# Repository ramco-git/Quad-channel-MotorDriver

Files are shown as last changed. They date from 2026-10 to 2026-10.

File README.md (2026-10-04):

# クアッドチャンネルモータードライバ (超はんだもりもり森鴎外!）

クアッドチャネルのDCブラシ付きモータードライバ基板です。内臓MCUにSTM32F405RGT6を使用し、4つのエンコーダ入力と1つのUART、1つのclassic CANに対応しています。内部でのPID制御が可能です。エンコーダはインクリメンタル式にのみ対応し、ゼロ校正に必要なZ相を引き出しています。すべての通信線は5Vトレラントピンに接続されています。入力信号をダイオードによりミックスしているため、内部から、又は外部から直接PWMとDIR信号を入力して動作させることができます。

## 仕様
・MCUにSTM32F405RGT6を使用し、回転数、位置制御を基板単体で可能です。
| 機能 | 個数 | 備考 |
|-:|-|-|
| モータードライバ | 4 | 30V、連続10A(なお性能試験を行っていないため、詳細は不明) |
| モーター出力 | 4 | XT60PW-F |
| 電源入力 | 1 | XT60PW-M |
|　MCU | 1 | STM32F405RGT6 |
| ユーザーLED | 1 | RGBの一体型チップ |
| ユーザーボタン | 1 | CANのID設定などに使用 |

## 信号線、マイコンのピンアサイン、コネクタの種類、番号
 
| 機能 | ピン | コネクタ種類 | パッドナンバー | 備考 |
|-:|-|-|-|-|
| CAN | TX(PB9) RX(PB8) | S04B-XASK-1,B04B-XASK-1 | J18,J19 | 
| UART | TX(PB10) RX(PB11) | DF1BZ-4P-2.5DSA | J6 |
| エンコーダ-1 | A(PA8) B(PA9) Z(PC0) | S05B-PASK-2 | J1 | TIM1 |
| エンコーダ-2 | A(PA0) B(PA1) Z(PC1) | S05B-PASK-2 | J2 | TIM2 |
| エンコーダ-3 | A(PA6) B(PA7) Z(PC2) | S05B-PASK-2 | J3 | TIM3 |
| エンコーダ-4 | A(PB6) B(PB7) Z(PC3) | S05B-PASK-2 | J4 | TIM4 |
| PWM-1(内臓MCUから) | PWM(PC6) DIR(PB12) | - | - | TIM8-CH1 |
| PWM-2(内臓MCUから) | PWM(PC7) DIR(PB13) | - | - | TIM8-CH2 |
| PWM-3(内臓MCUから) | PWM(PC8) DIR(PA10) | - | - | TIM8-CH3 |
| PWM-4(内臓MCUから) | PWM(PC9) DIR(PA11) | - | - | TIM8-CH4 |
| PWM-1(外部入力から) | DIR(1ピン) PWM(2ピン) GND(3ピン) | B03B-XASK-1 | J14 | - |
| PWM-2(外部入力から) | DIR(1ピン) PWM(2ピン) GND(3ピン) | B03B-XASK-1 | J15 | - |
| PWM-3(外部入力から) | DIR(1ピン) PWM(2ピン) GND(3ピン) | B03B-XASK-1 | J16 | - |
| PWM-4(外部入力から) | DIR(1ピン) PWM(2ピン) GND(3ピン) | B03B-XASK-1 | J17 | - |
| マイコン電源入力 | 12V(未使用,1ピン) 5V(2ピン) GND(3ピン) | B3B-XH-A | J7 | - |
| ユーザーLED | 赤(PB14) 緑(PA3) 青(PB15) | | D2 | TIMに接続されている |
| ユーザーボタン | (PC15) | - | SW2 | - | マイコン側でプルアップする |

## 内部ファームウェア
・現在調整中です。しばらくお待ちください。

## 名前の由来
大電流に対応させるため、銅線をバスバーとして使用した。その結果、基板がはんだだらけになってしまった。「超」はんだもりもり森鷗外!が誕生した。

## 以前の問題
・PWM,DIR信号ミックスに使用したBAT54CTのフットプリントのサイズミス
・部品番号の煩雑性

公開版では改善されています。

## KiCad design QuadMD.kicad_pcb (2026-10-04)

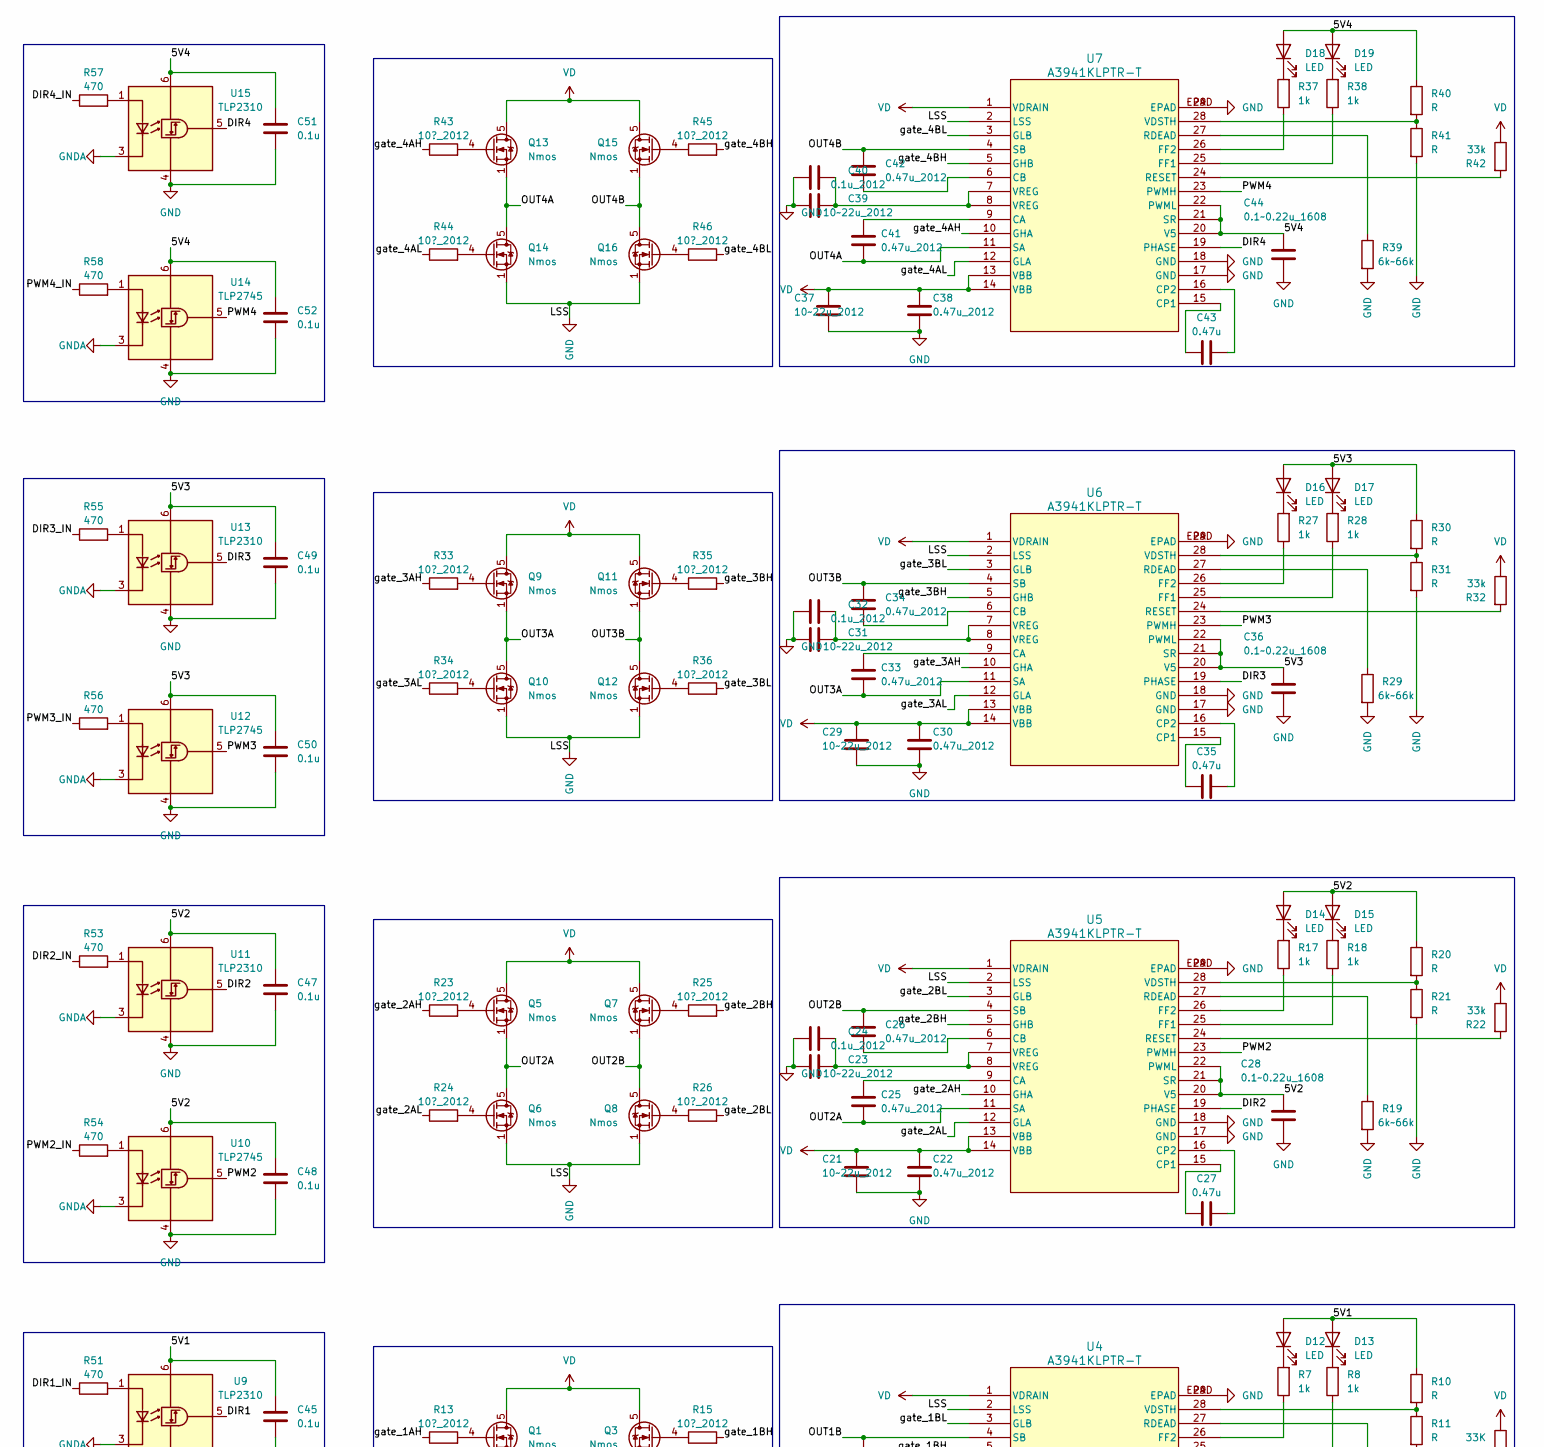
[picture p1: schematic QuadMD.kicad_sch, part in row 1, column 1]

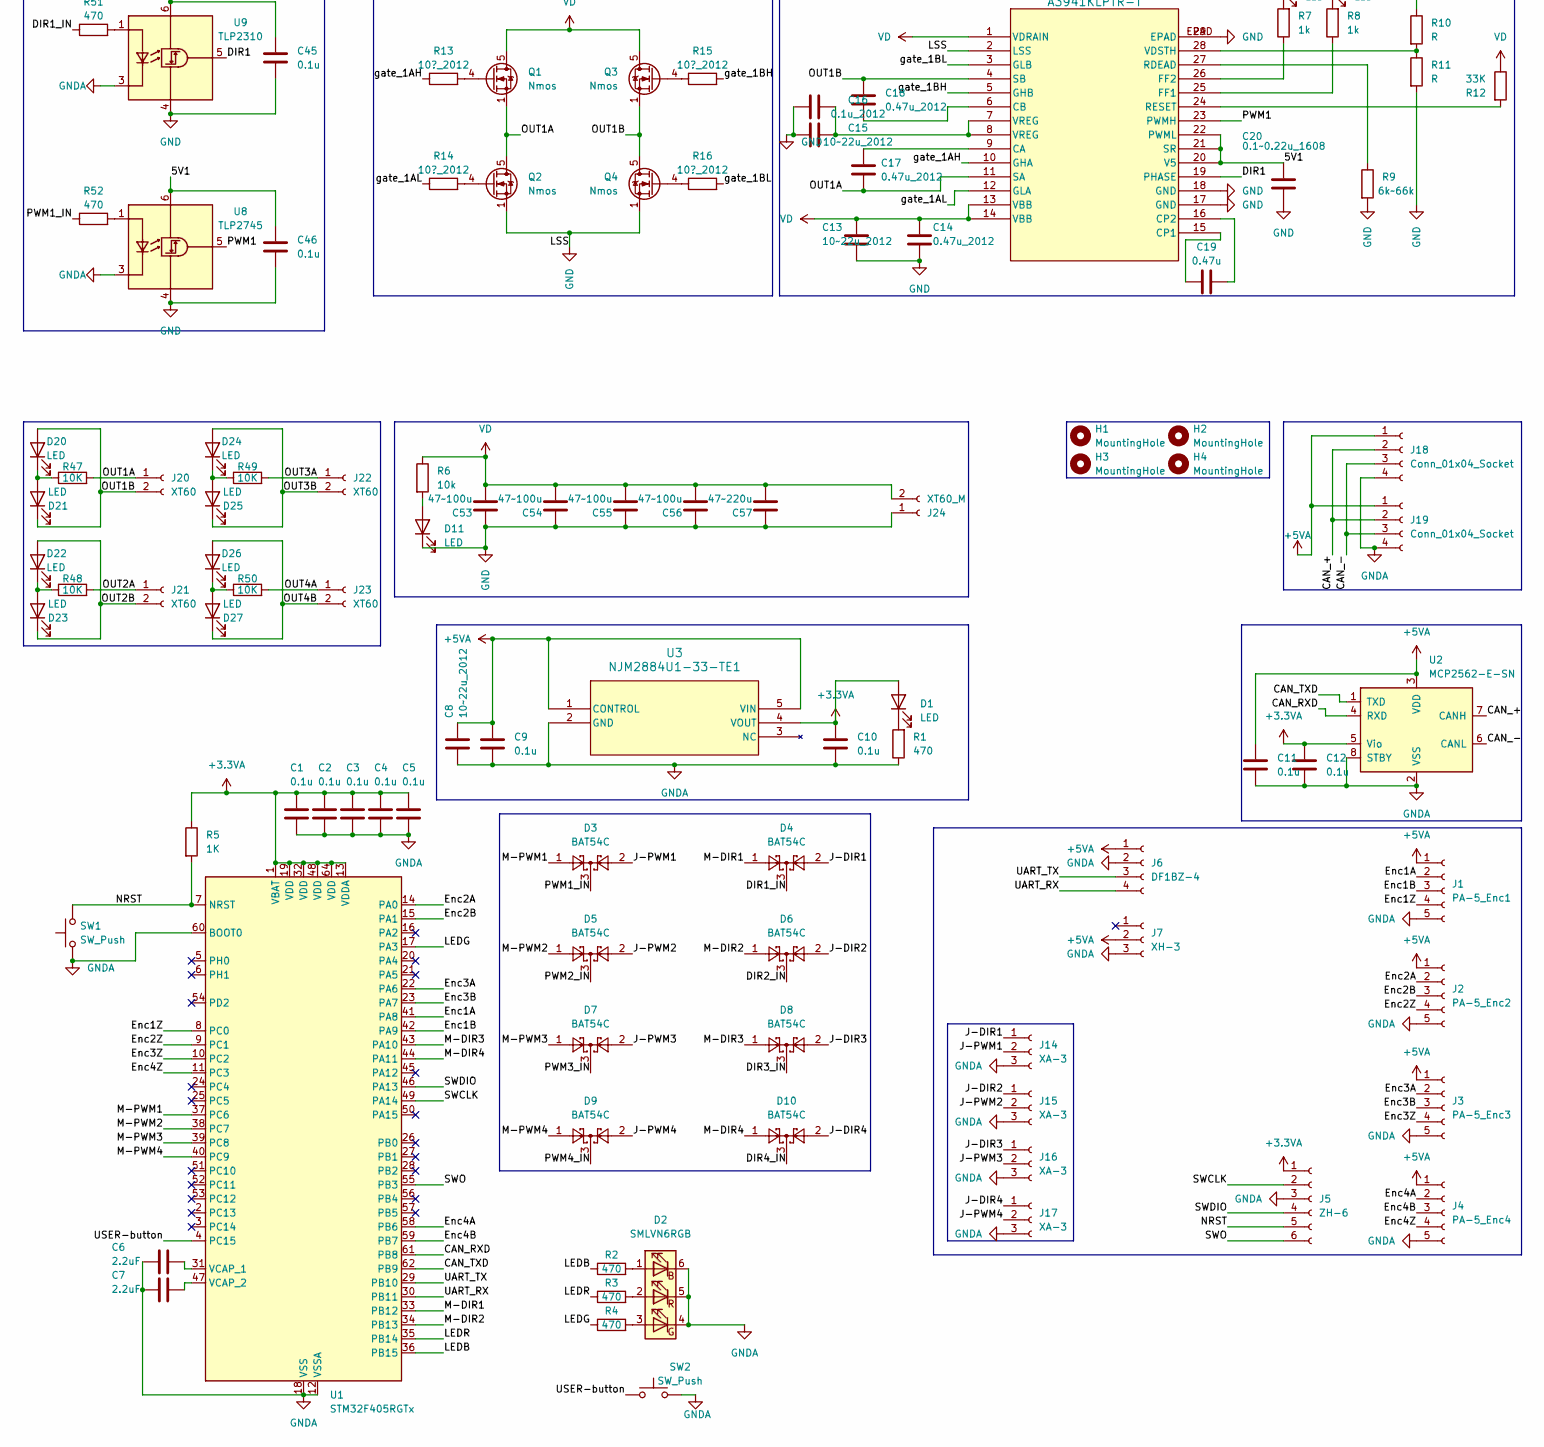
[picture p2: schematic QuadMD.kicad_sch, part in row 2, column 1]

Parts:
C1, C2, C3, C4, C5, C9, C10, C11, C12, C45, C46, C47, C48, C49, C50, C51, C52: 0.1u; C_0603_1608Metric
C6, C7: 2.2uF; C_0603_1608Metric
C8, C13, C15, C21, C23, C29, C31, C37, C39: 10~22u_2012; C_0805_2012Metric
C14, C17, C18, C22, C25, C26, C30, C33, C34, C38, C41, C42: 0.47u_2012; C_0805_2012Metric
C16, C24, C32, C40: 0.1u_2012; C_0805_2012Metric
C19, C27, C35, C43: 0.47u; C_0805_2012Metric
C20, C28, C36, C44: 0.1~0.22u_1608; C_0603_1608Metric
C53, C54, C55, C56: 47~100u; CP_Elec_6.3x5.7
C57: 47~220u; CP_Elec_10x10.5
D1, D11, D12, D13, D14, D15, D16, D17, D18, D19: LED; LED_0603_1608Metric
D2: SMLVN6RGB; LED_ROHM_SMLVN6
D3, D4, D5, D6, D7, D8, D9, D10: BAT54C; SOT-523
D20, D21, D22, D23, D24, D25, D26, D27: LED; LED_0805_2012Metric
H1, H2, H3, H4: MountingHole; MountingHole_M3_FBMask
J1: PA-5_Enc1; CONN_S05B-PASK_PA_JST
J2: PA-5_Enc2; CONN_S05B-PASK_PA_JST
J3: PA-5_Enc3; CONN_S05B-PASK_PA_JST
J4: PA-5_Enc4; CONN_S05B-PASK_PA_JST
J5: ZH-6; JST_ZH_B6B-ZR_1x06_P1.50mm_Vertical
J6: DF1BZ-4; CON4_1X4_U_DF1BZ
J7: XH-3; JST_XH_B3B-XH-A_1x03_P2.50mm_Vertical
J14, J15, J16, J17: XA-3; JST_XA_B03B-XASK-1_1x03_P2.50mm_Vertical
J18: Conn_01x04_Socket; JST_XA_B04B-XASK-1_1x04_P2.50mm_Vertical
J19: Conn_01x04_Socket; JST_XA_S04B-XASK-1N-BN_1x04_P2.50mm_Horizontal
J20, J21, J22, J23: XT60; AMASS_XT60PW-F_1x02_P7.20mm_Horizontal
J24: XT60_M; AMASS_XT60PW-M_1x02_P7.20mm_Horizontal
Q1, Q2, Q3, Q4, Q5, Q6, Q7, Q8, Q9, Q10, Q11, Q12, Q13, Q14, Q15, Q16: Nmos; PQFN-8-EP_6x5mm_P1.27mm_Generic
R1, R2, R3, R4, R51, R52, R53, R54, R55, R56, R57, R58: 470; R_0603_1608Metric
R5: 1K; R_0603_1608Metric
R6: 10k; R_0603_1608Metric
R7, R8, R17, R18, R27, R28, R37, R38: 1k; R_0603_1608Metric
R9, R19, R29, R39: 6k~66k; R_0603_1608Metric
R10, R11, R20, R21, R30, R31, R40, R41: R; R_0603_1608Metric
R12: 33K; R_0603_1608Metric
R13, R14, R15, R16, R23, R24, R25, R26, R33, R34, R35, R36, R43, R44, R45, R46: 10?_2012; R_0805_2012Metric
R22, R32, R42: 33k; R_0603_1608Metric
R47, R48, R49, R50: 10K; R_0603_1608Metric
SW1, SW2: SW_Push; SW_Push_SPST_NO_Alps_SKRK
U1: STM32F405RGTx; LQFP-64_10x10mm_P0.5mm
U2: MCP2562-E-SN; SOIC-8_3.9x4.9mm_P1.27mm
U3: NJM2884U1-33-TE1; SOT-89-5
U4, U5, U6, U7: A3941KLPTR-T; TSSOP-28-PAD_TH
U8, U10, U12, U14: TLP2745; SO-6L_10x3.84mm_P1.27mm
U9, U11, U13, U15: TLP2310; SO-5-6_4.55x3.7mm_P1.27mm

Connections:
+3.3VA: C1.1, C2.1, C3.1, C4.1, C5.1, C10.1, C12.1, D1.2 (A), J5.1, R5.1, U1.1 (VBAT), U1.13 (VDDA), U1.19 (VDD), U1.32 (VDD), U1.48 (VDD), U1.64 (VDD), U2.5 (Vio), U3.4 (VOUT)
+5VA: C8.1, C9.1, C11.1, J1.1, J2.1, J3.1, J4.1, J6.1, J7.2, J18.1, J19.1, U2.3 (VDD), U3.1 (CONTROL), U3.5 (VIN)
/5V1: C20.2, C45.2, C46.2, D12.2 (A), D13.2 (A), R10.1, U4.20 (V5), U4.21 (SR), U4.22 (PWML), U8.6 (VDD), U9.6 (VDD)
/5V2: C28.2, C47.2, C48.2, D14.2 (A), D15.2 (A), R20.1, U5.20 (V5), U5.21 (SR), U5.22 (PWML), U10.6 (VDD), U11.6 (VDD)
/5V3: C36.2, C49.2, C50.2, D16.2 (A), D17.2 (A), R30.1, U6.20 (V5), U6.21 (SR), U6.22 (PWML), U12.6 (VDD), U13.6 (VDD)
/5V4: C44.2, C51.2, C52.2, D18.2 (A), D19.2 (A), R40.1, U7.20 (V5), U7.21 (SR), U7.22 (PWML), U14.6 (VDD), U15.6 (VDD)
/CAN_+: J18.2, J19.2, U2.7 (CANH)
/CAN_-: J18.3, J19.3, U2.6 (CANL)
/CAN_RXD: U1.61 (PB8), U2.4 (RXD)
/CAN_TXD: U1.62 (PB9), U2.1 (TXD)
/DIR1: U4.19 (PHASE), U9.5 (VO)
/DIR1_IN: D4.3, R51.1
/DIR2: U5.19 (PHASE), U11.5 (VO)
/DIR2_IN: D6.3, R53.1
/DIR3: U6.19 (PHASE), U13.5 (VO)
/DIR3_IN: D8.3, R55.1
/DIR4: U7.19 (PHASE), U15.5 (VO)
/DIR4_IN: D10.3, R57.1
/Enc1A: J1.2, U1.41 (PA8)
/Enc1B: J1.3, U1.42 (PA9)
/Enc1Z: J1.4, U1.8 (PC0)
/Enc2A: J2.2, U1.14 (PA0)
/Enc2B: J2.3, U1.15 (PA1)
/Enc2Z: J2.4, U1.9 (PC1)
/Enc3A: J3.2, U1.22 (PA6)
/Enc3B: J3.3, U1.23 (PA7)
/Enc3Z: J3.4, U1.10 (PC2)
/Enc4A: J4.2, U1.58 (PB6)
/Enc4B: J4.3, U1.59 (PB7)
/Enc4Z: J4.4, U1.11 (PC3)
/J-DIR1: D4.2, J14.1
/J-DIR2: D6.2, J15.1
/J-DIR3: D8.2, J16.1
/J-DIR4: D10.2, J17.1
/J-PWM1: D3.2, J14.2
/J-PWM2: D5.2, J15.2
/J-PWM3: D7.2, J16.2
/J-PWM4: D9.2, J17.2
/LEDB: R2.1, U1.36 (PB15)
/LEDG: R4.1, U1.17 (PA3)
/LEDR: R3.1, U1.35 (PB14)
/M-DIR1: D4.1, U1.33 (PB12)
/M-DIR2: D6.1, U1.34 (PB13)
/M-DIR3: D8.1, U1.43 (PA10)
/M-DIR4: D10.1, U1.44 (PA11)
/M-PWM1: D3.1, U1.37 (PC6)
/M-PWM2: D5.1, U1.38 (PC7)
/M-PWM3: D7.1, U1.39 (PC8)
/M-PWM4: D9.1, U1.40 (PC9)
/NRST: J5.5, R5.2, SW1.2, U1.7 (NRST)
/OUT1A: C17.1, J20.1, Q1.1 (S), Q1.2 (S), Q1.3 (S), Q2.5 (D), R47.2, U4.11 (SA)
/OUT1B: C18.2, D20.2 (A), D21.1 (K), J20.2, Q3.1 (S), Q3.2 (S), Q3.3 (S), Q4.5 (D), U4.4 (SB)
/OUT2A: C25.1, J21.1, Q5.1 (S), Q5.2 (S), Q5.3 (S), Q6.5 (D), R48.2, U5.11 (SA)
/OUT2B: C26.2, D22.2 (A), D23.1 (K), J21.2, Q7.1 (S), Q7.2 (S), Q7.3 (S), Q8.5 (D), U5.4 (SB)
/OUT3A: C33.1, J22.1, Q9.1 (S), Q9.2 (S), Q9.3 (S), Q10.5 (D), R49.2, U6.11 (SA)
/OUT3B: C34.2, D24.2 (A), D25.1 (K), J22.2, Q11.1 (S), Q11.2 (S), Q11.3 (S), Q12.5 (D), U6.4 (SB)
/OUT4A: C41.1, J23.1, Q13.1 (S), Q13.2 (S), Q13.3 (S), Q14.5 (D), R50.2, U7.11 (SA)
/OUT4B: C42.2, D26.2 (A), D27.1 (K), J23.2, Q15.1 (S), Q15.2 (S), Q15.3 (S), Q16.5 (D), U7.4 (SB)
/PWM1: U4.23 (PWMH), U8.5 (VO)
/PWM1_IN: D3.3, R52.1
/PWM2: U5.23 (PWMH), U10.5 (VO)
/PWM2_IN: D5.3, R54.1
/PWM3: U6.23 (PWMH), U12.5 (VO)
/PWM3_IN: D7.3, R56.1
/PWM4: U7.23 (PWMH), U14.5 (VO)
/PWM4_IN: D9.3, R58.1
/SWCLK: J5.2, U1.49 (PA14)
/SWDIO: J5.4, U1.46 (PA13)
/SWO: J5.6, U1.55 (PB3)
/UART_RX: J6.4, U1.30 (PB11)
/UART_TX: J6.3, U1.29 (PB10)
/USER-button: SW2.1, U1.4 (PC15)
/gate_1AH: R13.1, U4.10 (GHA)
/gate_1AL: R14.1, U4.12 (GLA)
/gate_1BH: R15.2, U4.5 (GHB)
/gate_1BL: R16.2, U4.3 (GLB)
/gate_2AH: R23.1, U5.10 (GHA)
/gate_2AL: R24.1, U5.12 (GLA)
/gate_2BH: R25.2, U5.5 (GHB)
/gate_2BL: R26.2, U5.3 (GLB)
/gate_3AH: R33.1, U6.10 (GHA)
/gate_3AL: R34.1, U6.12 (GLA)
/gate_3BH: R35.2, U6.5 (GHB)
/gate_3BL: R36.2, U6.3 (GLB)
/gate_4AH: R43.1, U7.10 (GHA)
/gate_4AL: R44.1, U7.12 (GLA)
/gate_4BH: R45.2, U7.5 (GHB)
/gate_4BL: R46.2, U7.3 (GLB)
GND: C13.2, C14.2, C15.1, C16.1, C20.1, C21.2, C22.2, C23.1, C24.1, C28.1, C29.2, C30.2, C31.1, C32.1, C36.1, C37.2, C38.2, C39.1, C40.1, C44.1, C45.1, C46.1, C47.1, C48.1, C49.1, C50.1, C51.1, C52.1, C53.2, C54.2, C55.2, C56.2, C57.2, D11.1 (K), J24.1, Q2.1 (S), Q2.2 (S), Q2.3 (S), Q4.1 (S), Q4.2 (S), Q4.3 (S), Q6.1 (S), Q6.2 (S), Q6.3 (S), Q8.1 (S), Q8.2 (S), Q8.3 (S), Q10.1 (S), Q10.2 (S), Q10.3 (S), Q12.1 (S), Q12.2 (S), Q12.3 (S), Q14.1 (S), Q14.2 (S), Q14.3 (S), Q16.1 (S), Q16.2 (S), Q16.3 (S), R9.2, R11.2, R19.2, R21.2, R29.2, R31.2, R39.2, R41.2, U4.2 (LSS), U4.17 (GND), U4.18 (GND), U4.29 (EPAD), U4.EPAD, U5.2 (LSS), U5.17 (GND), U5.18 (GND), U5.29 (EPAD), U5.EPAD, U6.2 (LSS), U6.17 (GND), U6.18 (GND), U6.29 (EPAD), U6.EPAD, U7.2 (LSS), U7.17 (GND), U7.18 (GND), U7.29 (EPAD), U7.EPAD, U8.4 (GND), U9.4 (GND), U10.4 (GND), U11.4 (GND), U12.4 (GND), U13.4 (GND), U14.4 (GND), U15.4 (GND)
GNDA: C1.2, C2.2, C3.2, C4.2, C5.2, C6.1, C7.1, C8.2, C9.2, C10.2, C11.2, C12.2, D2.4 (GK), D2.5 (RK), D2.6 (BK), J1.5, J2.5, J3.5, J4.5, J5.3, J6.2, J7.3, J14.3, J15.3, J16.3, J17.3, J18.4, J19.4, R1.1, SW1.1, SW2.2, U1.12 (VSSA), U1.18 (VSS), U1.60 (BOOT0), U1.63 (VSS), U2.2 (VSS), U2.8 (STBY), U3.2 (GND), U8.3 (K), U9.3 (K), U10.3 (K), U11.3 (K), U12.3 (K), U13.3 (K), U14.3 (K), U15.3 (K)
unnamed: C15.2, C16.2, U4.7 (VREG), U4.8 (VREG)
unnamed: C23.2, C24.2, U5.7 (VREG), U5.8 (VREG)
unnamed: C31.2, C32.2, U6.7 (VREG), U6.8 (VREG)
unnamed: C39.2, C40.2, U7.7 (VREG), U7.8 (VREG)
unnamed: D1.1 (K), R1.2
unnamed: D2.1 (BA), R2.2
unnamed: D2.3 (GA), R4.2
unnamed: D2.2 (RA), R3.2
unnamed: D11.2 (A), R6.2
unnamed: D12.1 (K), R7.2
unnamed: D13.1 (K), R8.2
unnamed: D14.1 (K), R17.2
unnamed: D15.1 (K), R18.2
unnamed: D16.1 (K), R27.2
unnamed: D17.1 (K), R28.2
unnamed: D18.1 (K), R37.2
unnamed: D19.1 (K), R38.2
unnamed: D20.1 (K), D21.2 (A), R47.1
unnamed: D22.1 (K), D23.2 (A), R48.1
unnamed: D24.1 (K), D25.2 (A), R49.1
unnamed: D26.1 (K), D27.2 (A), R50.1
unnamed: Q1.4 (G), R13.2
unnamed: Q2.4 (G), R14.2
unnamed: Q3.4 (G), R15.1
unnamed: Q4.4 (G), R16.1
unnamed: Q5.4 (G), R23.2
unnamed: Q6.4 (G), R24.2
unnamed: Q7.4 (G), R25.1
unnamed: Q8.4 (G), R26.1
unnamed: Q9.4 (G), R33.2
unnamed: Q10.4 (G), R34.2
unnamed: Q11.4 (G), R35.1
unnamed: Q12.4 (G), R36.1
unnamed: Q13.4 (G), R43.2
unnamed: Q14.4 (G), R44.2
unnamed: Q15.4 (G), R45.1
unnamed: Q16.4 (G), R46.1
unnamed: C6.2, U1.31 (VCAP_1)
unnamed: C7.2, U1.47 (VCAP_2)
unnamed: C17.2, U4.9 (CA)
unnamed: C18.1, U4.6 (CB)
unnamed: C19.1, U4.15 (CP1)
unnamed: C19.2, U4.16 (CP2)
unnamed: R8.1, U4.25 (FF1)
unnamed: R7.1, U4.26 (FF2)
unnamed: R9.1, U4.27 (RDEAD)
unnamed: R12.2, U4.24 (RESET)
unnamed: R10.2, R11.1, U4.28 (VDSTH)
unnamed: C25.2, U5.9 (CA)
unnamed: C26.1, U5.6 (CB)
unnamed: C27.1, U5.15 (CP1)
unnamed: C27.2, U5.16 (CP2)
unnamed: R18.1, U5.25 (FF1)
unnamed: R17.1, U5.26 (FF2)
unnamed: R19.1, U5.27 (RDEAD)
unnamed: R22.2, U5.24 (RESET)
unnamed: R20.2, R21.1, U5.28 (VDSTH)
unnamed: C33.2, U6.9 (CA)
unnamed: C34.1, U6.6 (CB)
unnamed: C35.1, U6.15 (CP1)
unnamed: C35.2, U6.16 (CP2)
unnamed: R28.1, U6.25 (FF1)
unnamed: R27.1, U6.26 (FF2)
unnamed: R29.1, U6.27 (RDEAD)
unnamed: R32.2, U6.24 (RESET)
unnamed: R30.2, R31.1, U6.28 (VDSTH)
unnamed: C41.2, U7.9 (CA)
unnamed: C42.1, U7.6 (CB)
unnamed: C43.1, U7.15 (CP1)
unnamed: C43.2, U7.16 (CP2)
unnamed: R38.1, U7.25 (FF1)
unnamed: R37.1, U7.26 (FF2)
unnamed: R39.1, U7.27 (RDEAD)
unnamed: R42.2, U7.24 (RESET)
unnamed: R40.2, R41.1, U7.28 (VDSTH)
unnamed: R52.2, U8.1 (A)
unnamed: R51.2, U9.1 (A)
unnamed: R54.2, U10.1 (A)
unnamed: R53.2, U11.1 (A)
unnamed: R56.2, U12.1 (A)
unnamed: R55.2, U13.1 (A)
unnamed: R58.2, U14.1 (A)
unnamed: R57.2, U15.1 (A)
VD: C13.1, C14.1, C21.1, C22.1, C29.1, C30.1, C37.1, C38.1, C53.1, C54.1, C55.1, C56.1, C57.1, J24.2, Q1.5 (D), Q3.5 (D), Q5.5 (D), Q7.5 (D), Q9.5 (D), Q11.5 (D), Q13.5 (D), Q15.5 (D), R6.1, R12.1, R22.1, R32.1, R42.1, U4.1 (VDRAIN), U4.13 (VBB), U4.14 (VBB), U5.1 (VDRAIN), U5.13 (VBB), U5.14 (VBB), U6.1 (VDRAIN), U6.13 (VBB), U6.14 (VBB), U7.1 (VDRAIN), U7.13 (VBB), U7.14 (VBB)

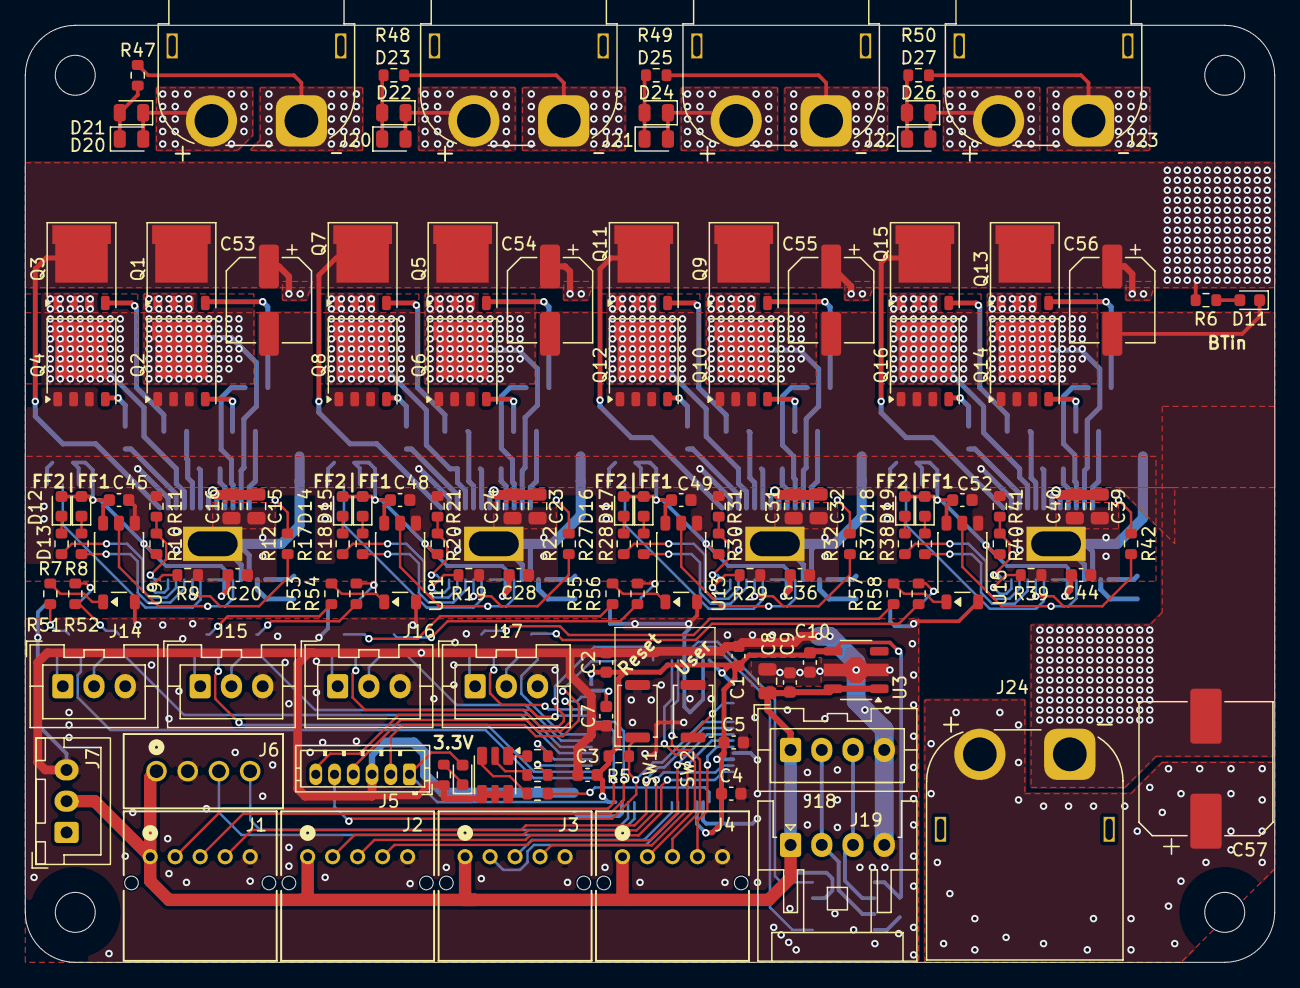
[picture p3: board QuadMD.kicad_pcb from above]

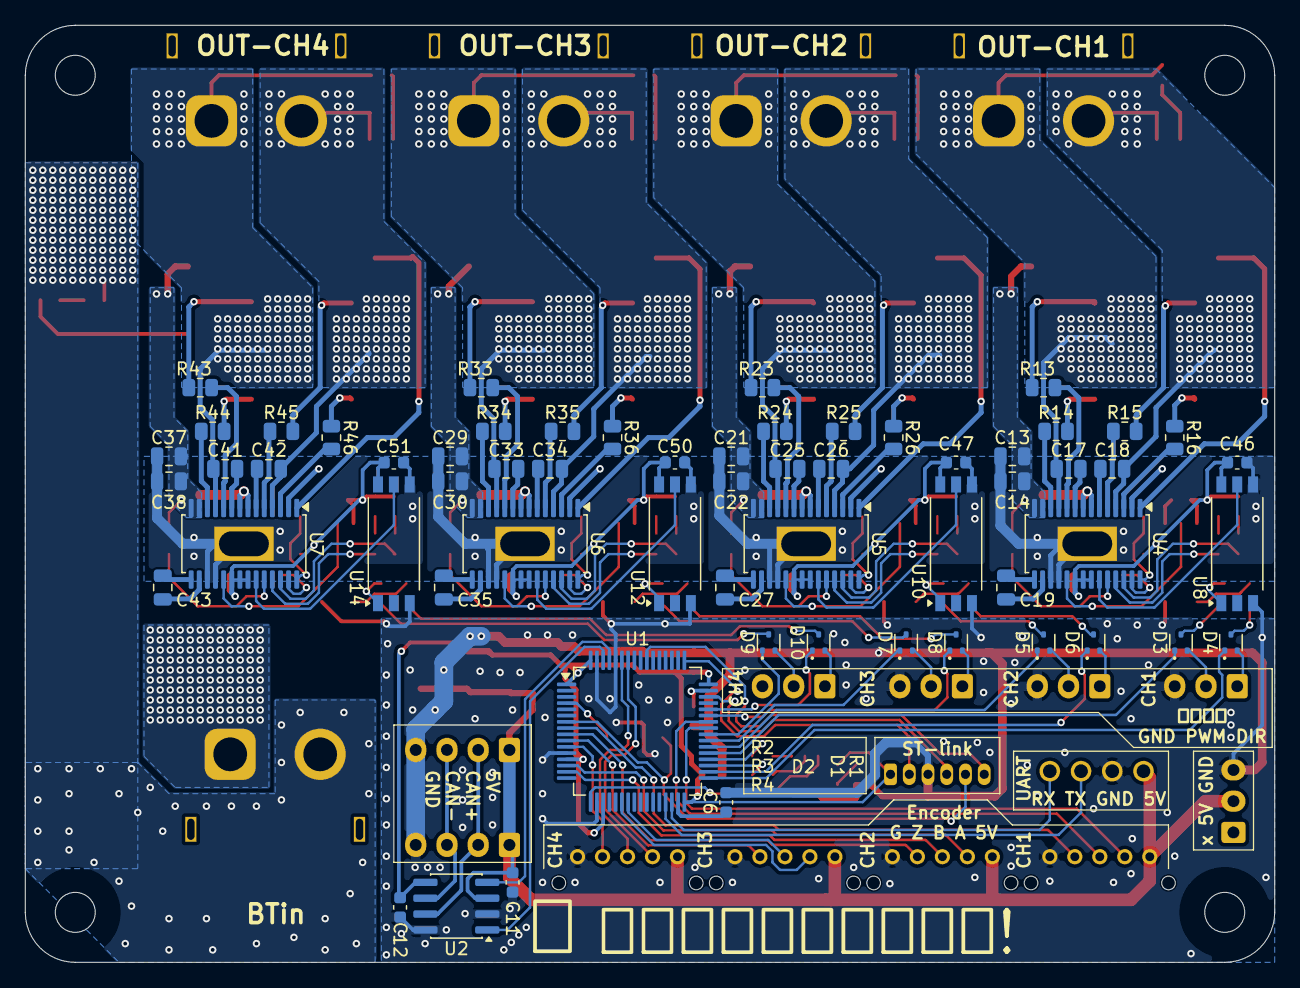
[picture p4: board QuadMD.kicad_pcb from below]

Board: 2 copper layers, 100.0 x 75.0 mm, 197 parts (61 on the bottom side), 174 nets.

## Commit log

2026-10-04 説明文追加
2026-10-04 Update PWM and user button descriptions in README
2026-10-04 Revise README for clarity and specification updates
    Updated the README to clarify specifications and wiring details.
2026-10-04 Update connector types and pin assignments in README
2026-10-04 README.md の更新
